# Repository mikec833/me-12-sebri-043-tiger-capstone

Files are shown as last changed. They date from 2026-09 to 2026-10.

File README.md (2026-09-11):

# The Tiger Challenge

Melbourne Zoo Sumatran tiger enrichment capstone — design context as of 11 September 2026.

## Purpose and concept

The project aims to develop a robotic enrichment system for Hutan, a Sumatran tiger at Melbourne Zoo. A mobile spherical robot is intended to encourage investigation, stalking, movement and play, then guide the tiger towards a separate feeder box that provides a food reward. Animal engagement and welfare benefits are intended outcomes, not yet demonstrated results.

The current concept uses two motor-driven internal wheels acting against the inside of a spherical shell. Differential wheel motion provides propulsion and steering. The ball carries its control electronics, sensors and battery; the food-release mechanism remains in the stationary feeder box. A speaker and amplifier are also planned for sound cues.

## Prototype and demonstration goals

A small, approximately 20 cm diameter ball is being used for early development. A larger ball is planned for the Endeavour exhibition; approximately 50 cm has been discussed, but final dimensions and hardware remain subject to mechanical development.

The intended demonstration is a robot moving within a defined space and triggering a simplified feeder box when it reaches the designated feeder zone. The box releases food or a substitute reward. This is a supervised prototype demonstration with no live tiger interaction, rather than evidence of readiness for enclosure deployment.

## System architecture

```text
Operator GUI / controller <-- wireless --> Raspberry Pi 3
                                              |
                                    UART commands / status
                                              |
                                            Teensy <-- motor encoders
                                              |
                                      Sabertooth 2x12
                                              |
                                    Two DC motors / wheels
                                              |
                                         Spherical shell

Fixed UWB anchors <--> onboard UWB tag --> localisation input to Pi
IMU / battery sensing -----------------> control and monitoring
Pi arrival logic ----------------------> separate feeder-box mechanism
Pi audio ------------------------------> amplifier --> speaker
```

| Component | Intended responsibility |
|---|---|
| Operator interface | Manual forward/reverse/turn/stop and variable speed; emergency stop; display mode, position, battery and faults. Waypoint selection and mode controls support later autonomy. |
| Raspberry Pi 3 | High-level state machine, operator communication, localisation, geofencing, navigation, feeder coordination and logging. Python is the proposed application language. |
| Teensy | Predictable motor-control timing, encoder acquisition, left/right speed targets, closed-loop speed regulation, command-timeout stopping and motor fault handling. Firmware is expected to use C/C++. |
| Sabertooth 2x12 | Converts controller commands into motor power. The exact input mode and signalling must be confirmed before wiring and implementation; earlier notes use “PWM/direction” as shorthand. |
| Power system | Planned rechargeable battery with protected motor supply and regulated electronics supplies. Current measurements will inform battery and regulator sizing. |

The proposed software uses **timed control loops plus asynchronous sensor updates**. The Pi runs a supervisory loop; callbacks or background tasks update timestamped sensor and command data. The Teensy runs a fixed-rate motor loop, with interrupts for encoder pulses. Illustrative starting rates are 10–30 Hz for supervision and 50–100 Hz for motor control, to be validated experimentally.

Only the Pi's supervisory logic selects the final requested motion; the Teensy applies motor control and local safety overrides. Sensor callbacks do not independently command motion. Suggested states are idle, manual control, autonomous navigation, geofence avoidance, fault and emergency stop.

## Sensors and interfaces

- **Ultra-wideband (UWB):** fixed anchors and one mobile tag provide position for navigation, exclusion zones and feeder proximity. Qorvo modules/development kits have been considered; hardware, anchor layout and the Pi interface still need confirmation. Accuracy must be measured with the shell, obstructions and intended environment.
- **Inertial measurement unit (IMU):** the BNO085 breakout has been discussed for orientation, angular rate, rocking measurement and possible interaction detection. Its controller connection and role in heading estimation remain to be finalised.
- **Motor encoders:** provide left/right speed feedback to the Teensy. Wheel rotation alone does not establish ball displacement because the wheels can slip against the shell.
- **Battery voltage sensing:** supports telemetry and low-voltage stopping. Motor-current sensing is a possible addition for power characterisation and fault detection.
- **Optional obstacle sensors:** time-of-flight, lidar and ultrasonic options have been explored. Mounting and sensing through a rotating shell remain unresolved.

The planned Pi–Teensy link is UART, carrying speed/turn/stop commands and returning encoder speeds, status and faults. Operator communication is expected to use Wi-Fi; alternatives remain under evaluation. Sensor fusion, including a possible Kalman filter, is an enhancement rather than an established implementation. UWB position alone does not supply heading.

## Feeder-box interaction

The longer-term sequence is: attract engagement → detect distinct tiger interactions → navigate to the selected feeder → stop in its arrival zone → request food release. One feeder is planned for prototyping, with multiple feeders a possible extension.

Draft requirements propose **three interactions separated by 30 seconds** and a **0.5 m feeder-arrival threshold**. These are provisional values to validate; older notes also mention five interactions. Detection must distinguish animal contact from driving, terrain disturbances and the robot's own rocking.

For the exhibition, reaching the feeder zone is the essential trigger; reliable tiger-interaction recognition is not a prerequisite. The feeder communication link, actuator, release confirmation and protection against repeated releases still require detailed design.

## Safety approach

The intended behaviour is stopped on startup/reset, emergency-stop priority over all movement commands, and a Teensy watchdog that stops the motors if fresh Pi commands cease. Operator-link loss must also propagate to a stop. Invalid or stale localisation prevents autonomous movement.

The Pi applies speed/acceleration limits and exclusion zones for the pond, enclosure boundary and high-risk terrain. Margins must account for localisation uncertainty and stopping distance. Battery monitoring and stall/fault detection support safe stopping; encoder-only stall detection cannot detect every slipping or trapped condition.

Emergency return is a separate proposed navigation feature and must never override an emergency stop. Mechanical containment, electrical protection and operating limits require validation before any animal trial. Exhibition operation is low-speed, supervised and confined to a controlled area, with no public handling.

## MVP and stretch scope

| Priority | Scope |
|---|---|
| Core MVP | Reliable manual driving, motor control, encoder feedback, UWB position input, basic geofencing, emergency stop, communication-loss stop and useful data logging. |
| Exhibition integration | Demonstrate movement in a defined area and repeatable arrival-triggered release from one feeder box. |
| Next-stage goals | Closed-loop performance tuning, basic waypoint navigation, safe manual/autonomous mode transitions and validated IMU-based interaction detection. |
| Stretch goals | Dynamic obstacle avoidance/path planning, richer sensor fusion, multiple feeders, camera display, emergency return and more elaborate enrichment behaviour. |

Earlier notes classify some features inconsistently, particularly mode switching and stall detection. This table expresses implementation priorities; it does not remove the need to address faults relevant to the chosen demonstration.

## Testing approach

1. **Bench tests:** verify motor direction and stopping, encoder sign/scaling, command-to-speed response and current draw. Start with open-loop characterisation before tuning feedback control.
2. **Small-ball tests:** measure traction, slip, steering and forward/backward rocking under load. Log commands, encoder speeds, IMU data and supply conditions; use these to identify the relevant dynamics and evaluate speed control and rate damping.
3. **Module and fault tests:** exercise localisation validity, geofence decisions, startup/reset, emergency stop, dropped commands, sensor loss and battery/fault handling.
4. **Integrated demonstration:** repeat travel and feeder arrival/release trials, including noisy boundary readings and repeated zone entry. Record arrival error, stopping behaviour and unintended releases.
5. **Larger prototype:** repeat identification, power measurements and controller tuning. The development method may transfer from the small ball; numerical models and gains must be revalidated.

Log timestamps, mode/state, targets, motor commands, measured speeds, UWB/IMU data, battery voltage and faults. Set measurable acceptance limits before final testing; current notes do not establish validated performance figures.

## Current development status

The project is in detailed design and early hardware/control development. A small prototype exists and noticeable forward/backward swaying has been reported. The latest discussions concern Raspberry Pi setup, motor-driver testing, current measurement, low-level controller design and integrating sensors through the two-controller architecture. Michael is leading control/software work.

There is no confirmed end-to-end demonstration, validated safety performance or completed autonomous system in the available context. Immediate work is to establish repeatable motor/encoder tests, validate power requirements, tune motion on the small ball, and integrate localisation, stopping behaviour and the feeder link in stages.

This workspace currently contains reference material and this README, not a runnable software release. Files under `sources/` are read-only synced references. This summary follows the project conversation, prioritising recent decisions and marking unresolved details rather than treating earlier suggestions as completed work.

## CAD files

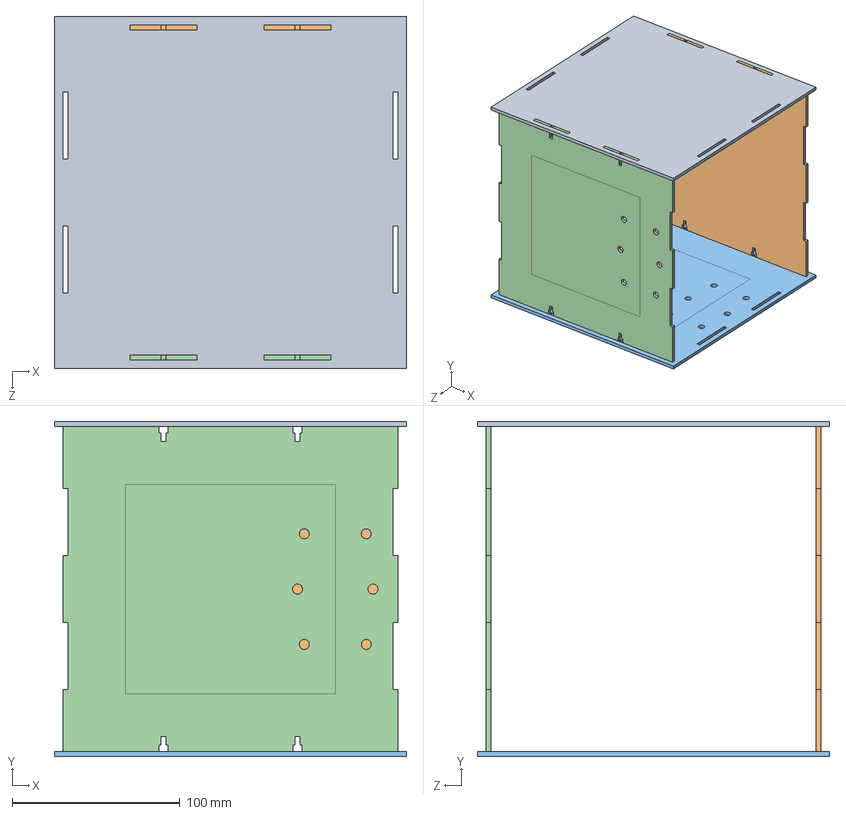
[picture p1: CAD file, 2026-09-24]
CAD File/Feeding Box CAD/Accessable.SLDASM
210.0 x 200.1 x 210.0 mm
Front
Base
Back
Top

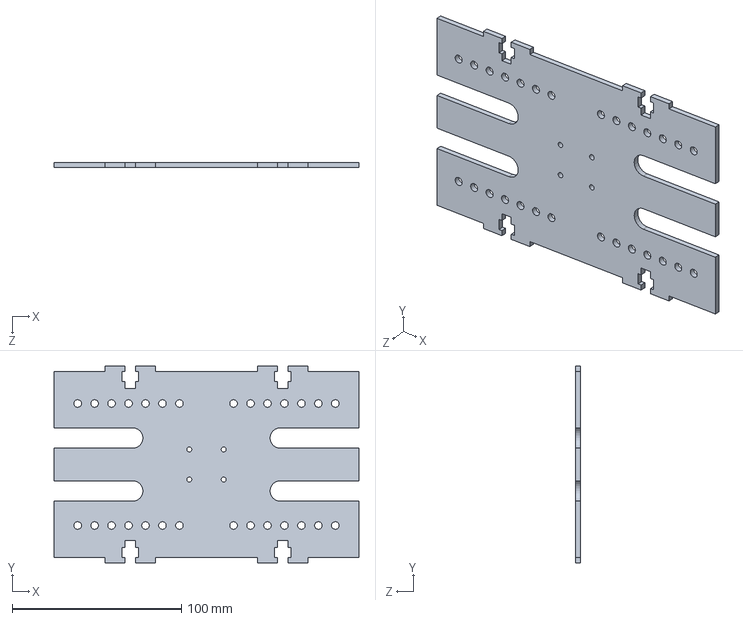
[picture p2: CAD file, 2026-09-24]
CAD File/Gig Ball Robot CAD/01_Main_Plate_3mm.SLDPRT
180.0 x 116.0 x 3.00 mm

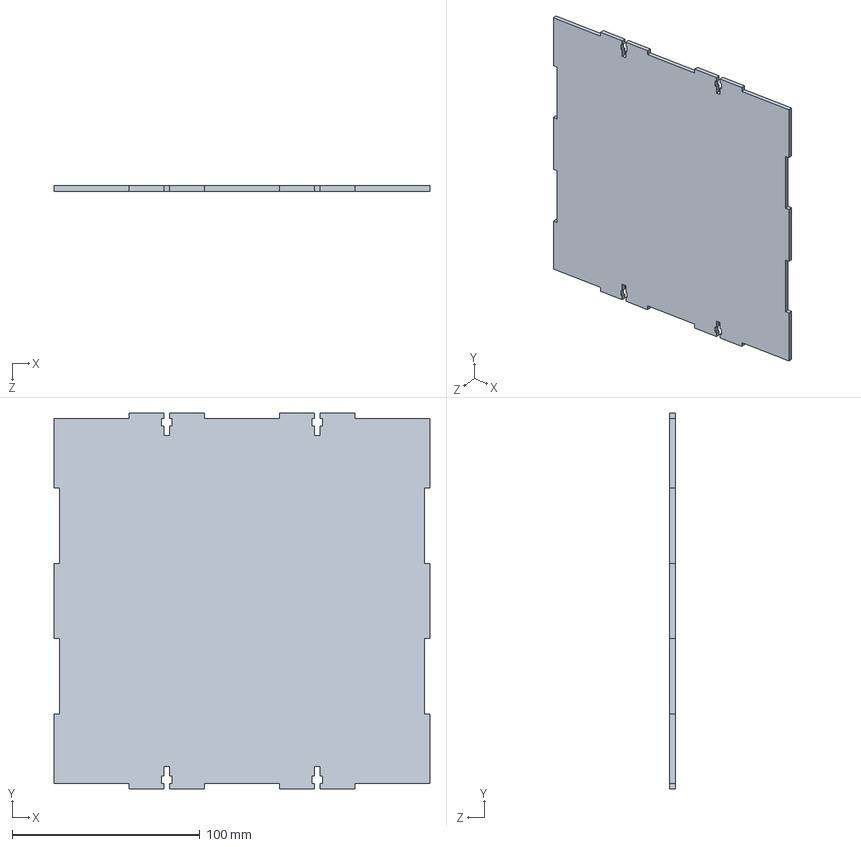
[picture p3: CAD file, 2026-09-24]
CAD File/Feeding Box CAD/Back.SLDPRT
200.0 x 200.0 x 3.00 mm

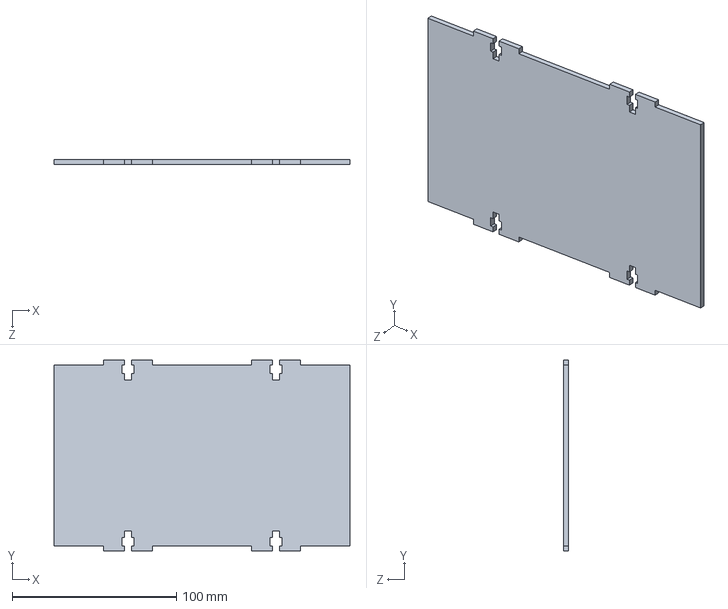
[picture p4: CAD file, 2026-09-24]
CAD File/Gig Ball Robot CAD/03_Standard_Electronics_Layer_3mm.SLDPRT
180.0 x 116.0 x 3.00 mm

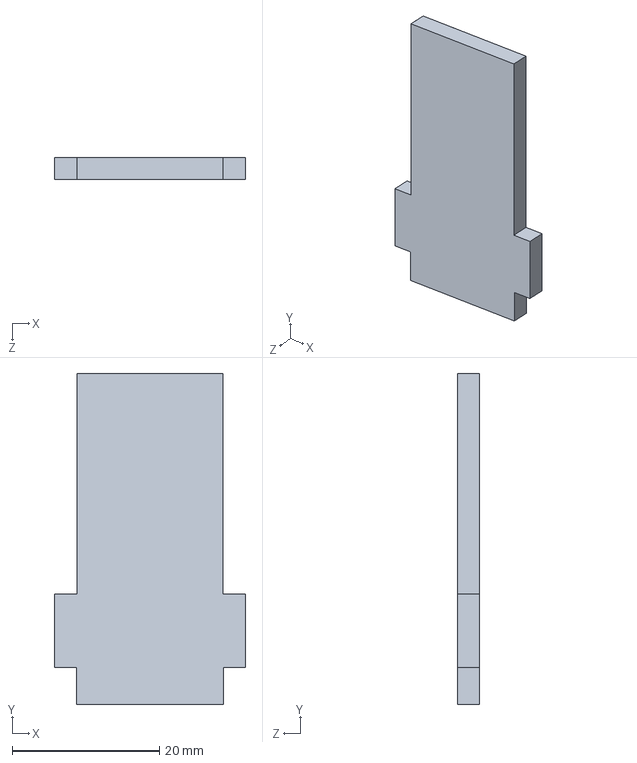
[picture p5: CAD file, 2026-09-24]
CAD File/Small Ball Robot CAD/Base Arm.SLDPRT
26.0 x 45.0 x 3.00 mm

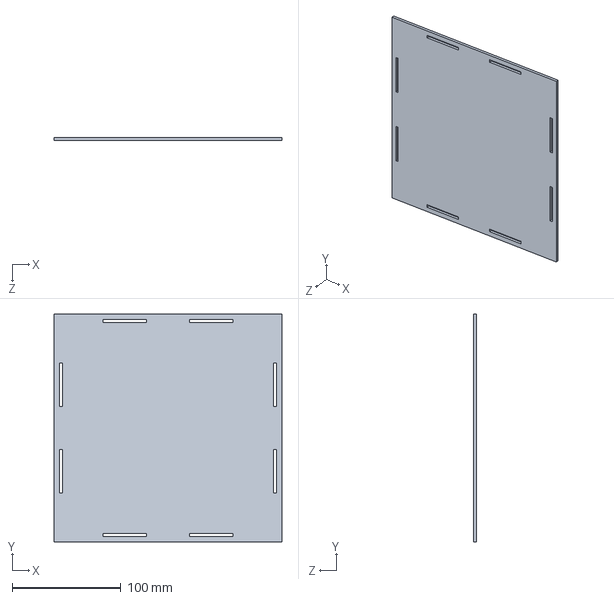
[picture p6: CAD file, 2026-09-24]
CAD File/Feeding Box CAD/Top.SLDPRT
210.0 x 210.0 x 3.00 mm

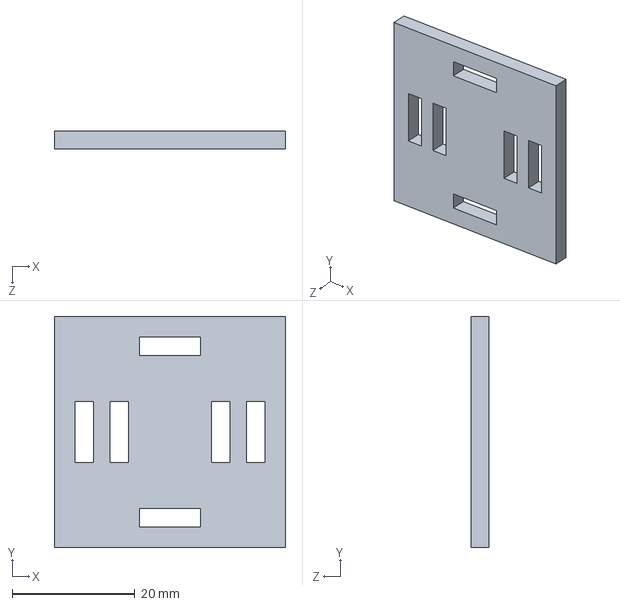
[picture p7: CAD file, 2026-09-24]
CAD File/Gig Ball Robot CAD/09_Spring_Top_Cover_3mm.SLDPRT
37.6 x 37.6 x 3.00 mm

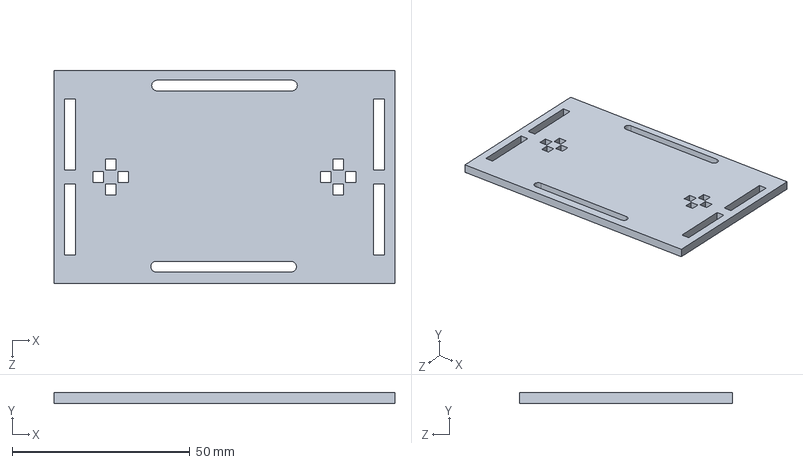
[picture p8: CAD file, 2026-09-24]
CAD File/Small Ball Robot CAD/Chasis Upper Base.SLDPRT
96.0 x 3.00 x 60.0 mm

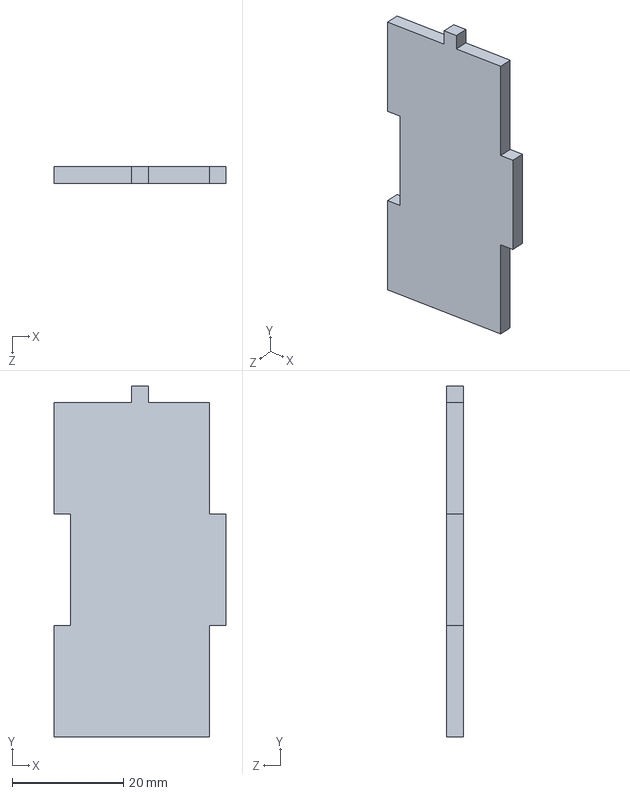
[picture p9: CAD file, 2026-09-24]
CAD File/Gig Ball Robot CAD/08_Moving_Spring_Housing_Wall_3mm.SLDPRT
30.9 x 63.0 x 3.00 mm

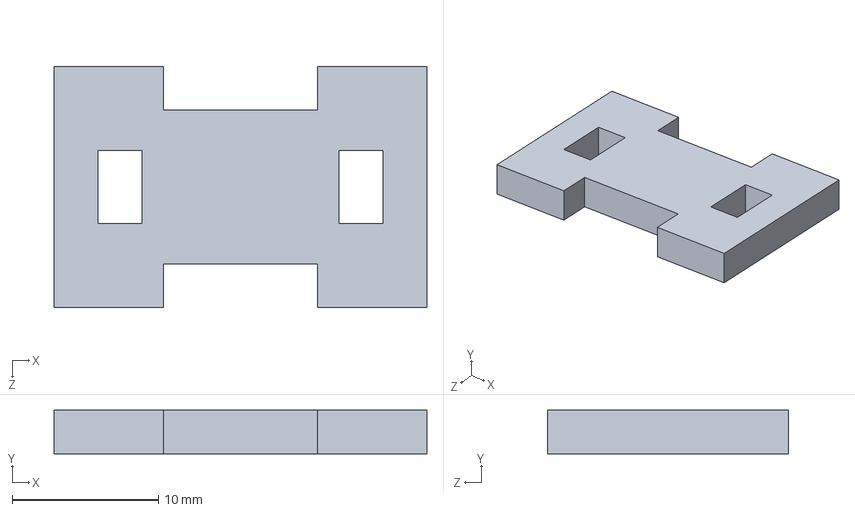
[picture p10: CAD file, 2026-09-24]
CAD File/Small Ball Robot CAD/Sping Top Cover.SLDPRT
25.5 x 3.00 x 16.5 mm

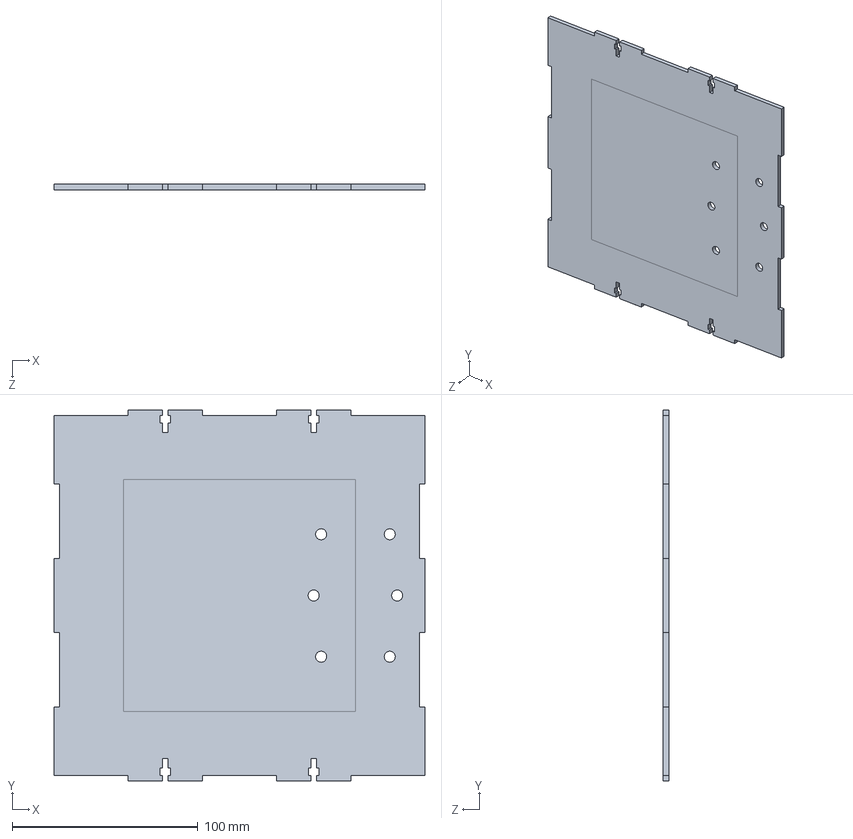
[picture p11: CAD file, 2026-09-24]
CAD File/Feeding Box CAD/Front.SLDPRT
200.0 x 200.0 x 3.00 mm

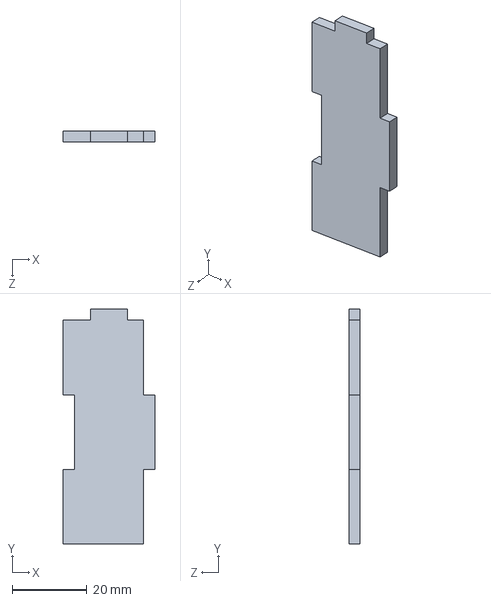
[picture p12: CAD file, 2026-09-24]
CAD File/Gig Ball Robot CAD/07_Fixed_Spring_Guide_Wall_3mm.SLDPRT
24.6 x 63.0 x 3.00 mm

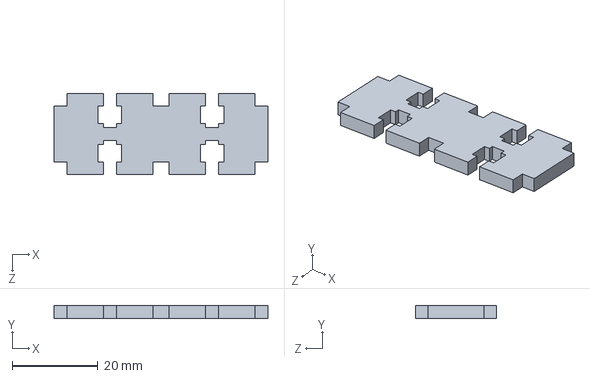
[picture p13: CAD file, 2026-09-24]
CAD File/Small Ball Robot CAD/Weight Support.SLDPRT
50.0 x 3.00 x 19.0 mm

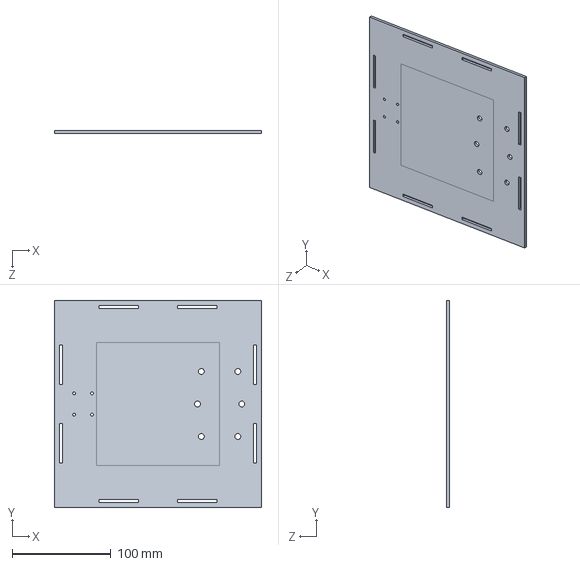
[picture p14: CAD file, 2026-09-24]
CAD File/Feeding Box CAD/Base.SLDPRT
210.0 x 210.0 x 3.00 mm

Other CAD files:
CAD File/Gig Ball Robot CAD/TigerBall_Chassis_220mm_Track_Editable.SLDASM
CAD File/Small Ball Robot CAD/Assembled Spring Support.SLDASM
CAD File/Gig Ball Robot CAD/02_Motor_Carrier_3mm.SLDPRT
CAD File/Small Ball Robot CAD/Wheel Support.SLDPRT
CAD File/Feeding Box CAD/Sides.SLDPRT
CAD File/Gig Ball Robot CAD/04_Raspberry_Pi_3_Layer_3mm.SLDPRT
CAD File/Gig Ball Robot CAD/05_Extended_Sideboard_322mm_3mm.SLDPRT
CAD File/Gig Ball Robot CAD/06_Dual_Spring_Shelf_3mm.SLDPRT
CAD File/Gig Ball Robot CAD/10_Upper_Wheel_Fork_3mm.SLDPRT
CAD File/Gig Ball Robot CAD/11_Battery_Plate_3mm.SLDPRT
CAD File/Gig Ball Robot CAD/Spring Wheel.SLDPRT
CAD File/Gig Ball Robot CAD/Spring_Cover_Front.SLDPRT
CAD File/Gig Ball Robot CAD/Spring_Cover_Side.SLDPRT
CAD File/Gig Ball Robot CAD/Wheel_Support.SLDPRT
CAD File/Small Ball Robot CAD/Battery Base.SLDPRT
CAD File/Small Ball Robot CAD/Battery Support.SLDPRT
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

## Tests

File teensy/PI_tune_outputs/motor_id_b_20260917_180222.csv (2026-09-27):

t_ms | refL | refR | cmdL | cmdR | countL | countR | thdotL | thdotR
10 | 0.00 | 0.00 | 0.00 | 0.00 | 0 | 0 | 0.000 | 0.000
20 | 0.00 | 0.00 | 0.00 | 0.00 | 0 | 0 | 0.000 | 0.000
30 | 0.00 | 0.00 | 0.00 | 0.00 | 0 | 0 | 0.000 | 0.000
40 | 0.00 | 0.00 | 0.00 | 0.00 | 0 | 0 | 0.000 | 0.000
50 | 0.00 | 0.00 | 0.00 | 0.00 | 0 | 0 | 0.000 | 0.000
60 | 0.00 | 0.00 | 0.00 | 0.00 | 0 | 0 | 0.000 | 0.000
70 | 0.00 | 0.00 | 0.00 | 0.00 | 0 | 0 | 0.000 | 0.000
80 | 0.00 | 0.00 | 0.00 | 0.00 | 0 | 0 | 0.000 | 0.000
90 | 0.00 | 0.00 | 0.00 | 0.00 | 0 | 0 | 0.000 | 0.000
100 | 0.00 | 0.00 | 0.00 | 0.00 | 0 | 0 | 0.000 | 0.000
110 | 0.00 | 0.00 | 0.00 | 0.00 | 0 | 0 | 0.000 | 0.000
120 | 0.00 | 0.00 | 0.00 | 0.00 | 0 | 0 | 0.000 | 0.000
130 | 0.00 | 0.00 | 0.00 | 0.00 | 0 | 0 | 0.000 | 0.000
140 | 0.00 | 0.00 | 0.00 | 0.00 | 0 | 0 | 0.000 | 0.000
150 | 0.00 | 0.00 | 0.00 | 0.00 | 0 | 0 | 0.000 | 0.000
160 | 0.00 | 0.00 | 0.00 | 0.00 | 0 | 0 | 0.000 | 0.000
170 | 0.00 | 0.00 | 0.00 | 0.00 | 0 | 0 | 0.000 | 0.000
180 | 0.00 | 0.00 | 0.00 | 0.00 | 0 | 0 | 0.000 | 0.000
190 | 0.00 | 0.00 | 0.00 | 0.00 | 0 | 0 | 0.000 | 0.000
200 | 0.00 | 0.00 | 0.00 | 0.00 | 0 | 0 | 0.000 | 0.000
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

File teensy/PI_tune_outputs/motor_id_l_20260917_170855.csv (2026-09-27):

t_ms | cmdL | cmdR | countL | countR | thdotL | thdotR
10 | 0 | 0 | 4 | 0 | 0.561 | 0.000
20 | 0 | 0 | 9 | 0 | 0.701 | 0.000
30 | 0 | 0 | 14 | 0 | 0.701 | 0.000
40 | 0 | 0 | 19 | 0 | 0.701 | 0.000
50 | 0 | 0 | 23 | 0 | 0.561 | 0.000
60 | 0 | 0 | 28 | 0 | 0.701 | 0.000
70 | 0 | 0 | 33 | 0 | 0.701 | 0.000
80 | 0 | 0 | 37 | 0 | 0.561 | 0.000
90 | 0 | 0 | 42 | 0 | 0.701 | 0.000
100 | 0 | 0 | 46 | 0 | 0.561 | 0.000
110 | 0 | 0 | 49 | 0 | 0.421 | 0.000
120 | 0 | 0 | 53 | 0 | 0.561 | 0.000
130 | 0 | 0 | 57 | 0 | 0.561 | 0.000
140 | 0 | 0 | 60 | 0 | 0.421 | 0.000
150 | 0 | 0 | 63 | 0 | 0.421 | 0.000
160 | 0 | 0 | 67 | 0 | 0.561 | 0.000
170 | 0 | 0 | 71 | 0 | 0.561 | 0.000
180 | 0 | 0 | 75 | 0 | 0.561 | 0.000
190 | 0 | 0 | 78 | 0 | 0.421 | 0.000
200 | 0 | 0 | 82 | 0 | 0.561 | 0.000
210 | 0 | 0 | 86 | 0 | 0.561 | 0.000
220 | 0 | 0 | 89 | 0 | 0.421 | 0.000
230 | 0 | 0 | 93 | 0 | 0.561 | 0.000
240 | 0 | 0 | 96 | 0 | 0.421 | 0.000
250 | 0 | 0 | 100 | 0 | 0.561 | 0.000
260 | 0 | 0 | 104 | 0 | 0.561 | 0.000
270 | 0 | 0 | 109 | 0 | 0.701 | 0.000
280 | 0 | 0 | 114 | 0 | 0.701 | 0.000
290 | 0 | 0 | 118 | 0 | 0.561 | 0.000
300 | 0 | 0 | 123 | 0 | 0.701 | 0.000
310 | 0 | 0 | 128 | 0 | 0.701 | 0.000
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

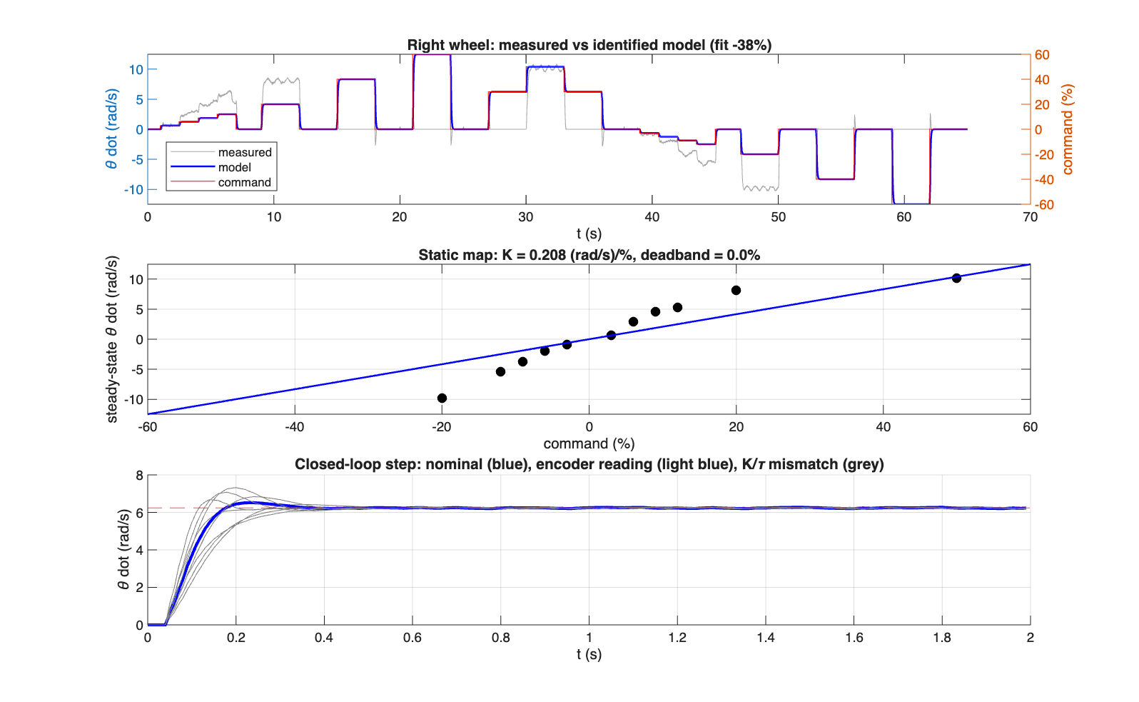
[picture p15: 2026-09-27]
teensy/PI_tune_outputs/right_run1_60pc.png

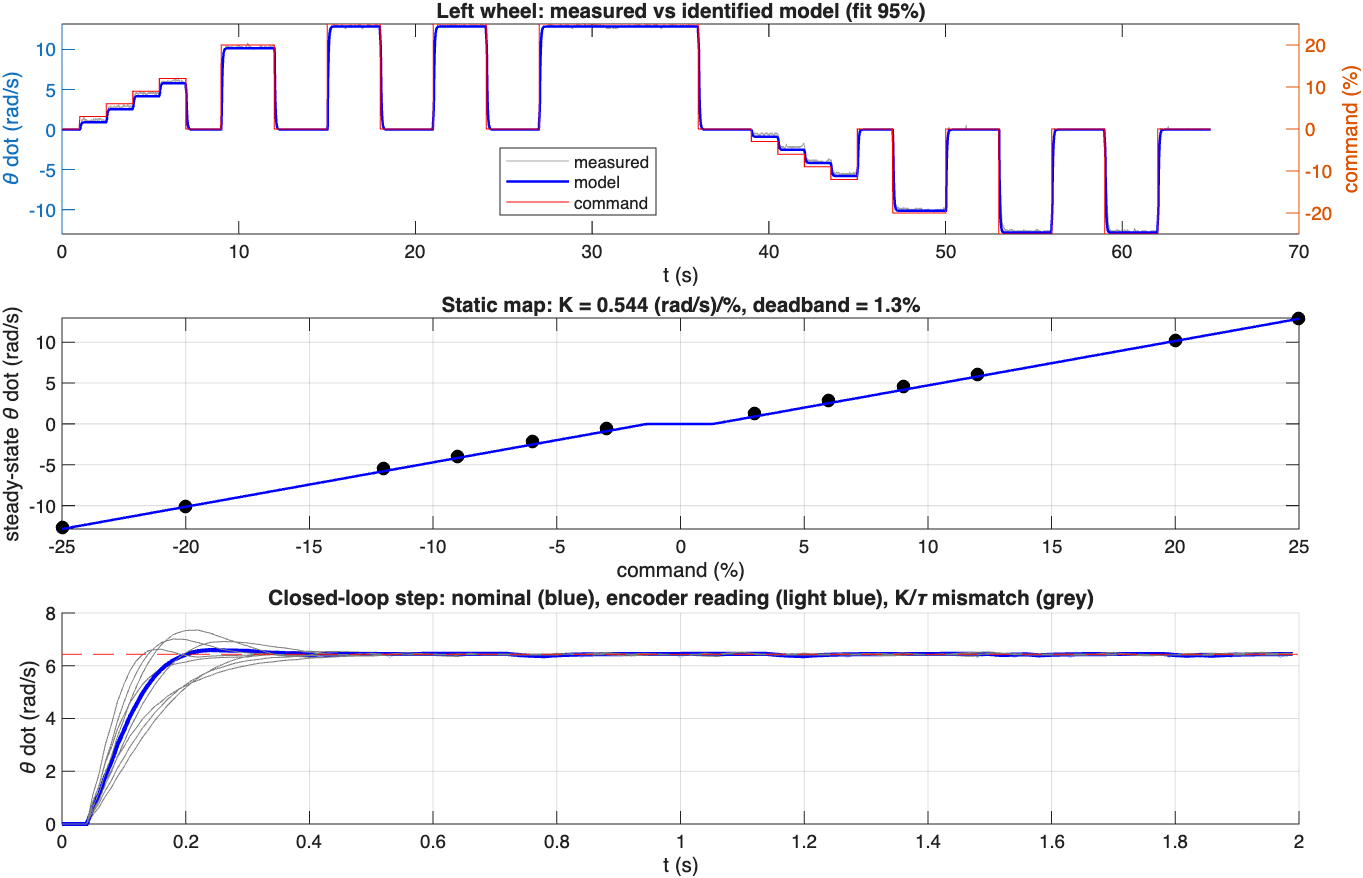
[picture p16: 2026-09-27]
teensy/PI_tune_outputs/left_run2_25pc.png

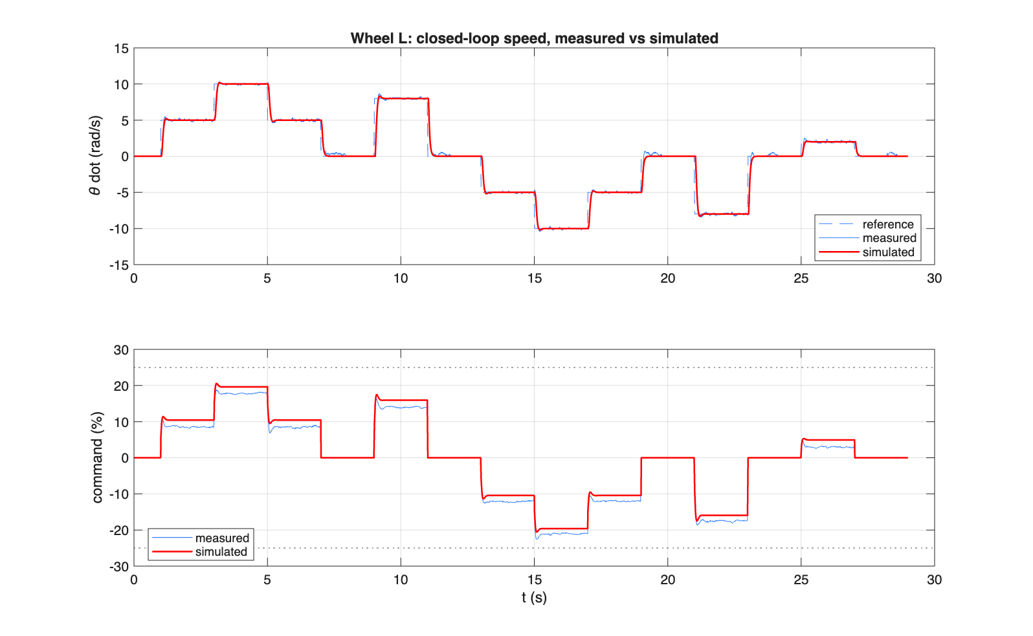
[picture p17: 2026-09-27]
teensy/PI_tune_outputs/CL_left_run_comp.png

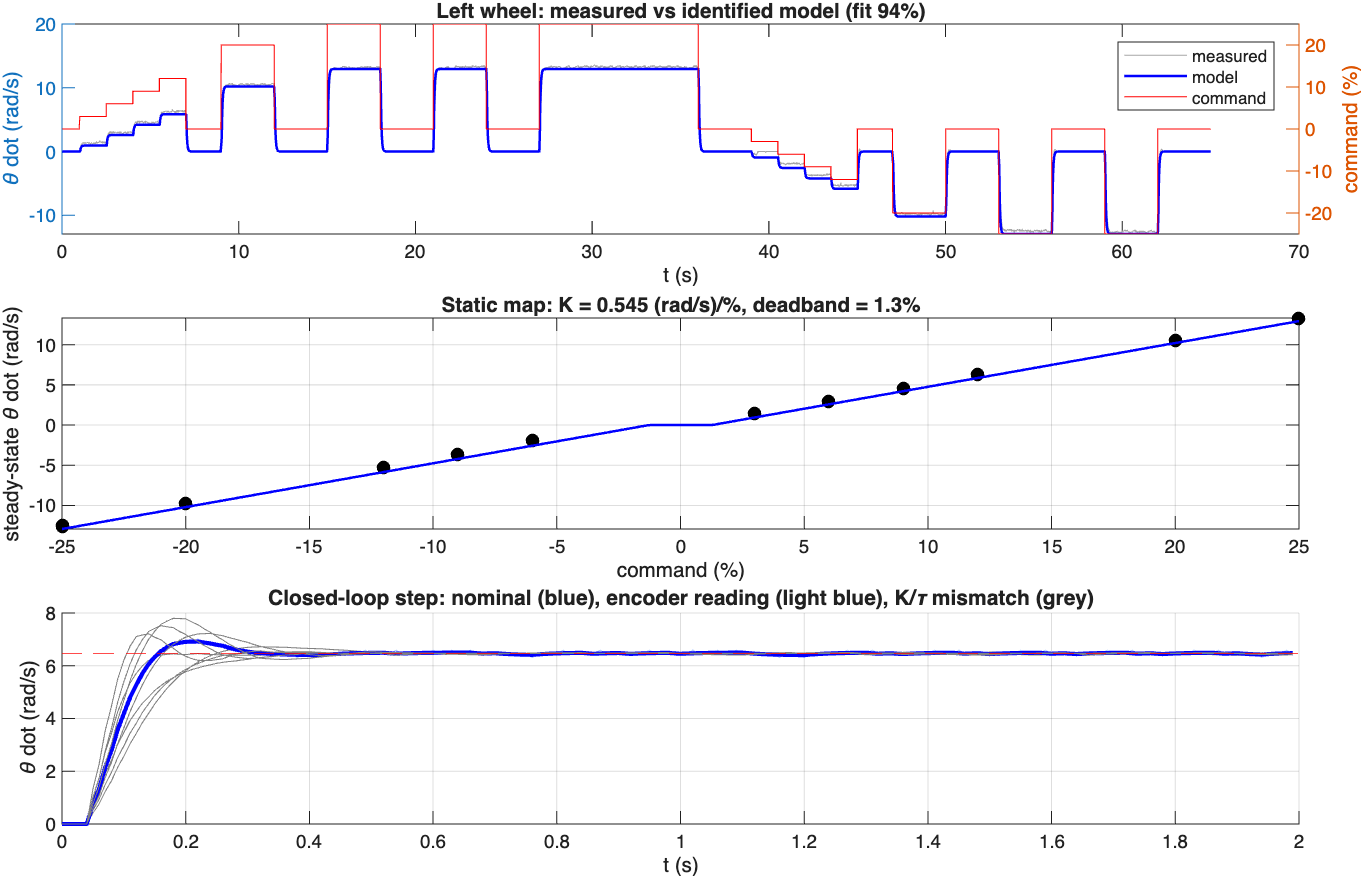
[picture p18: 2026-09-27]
teensy/PI_tune_outputs/left_run3_25pc.png

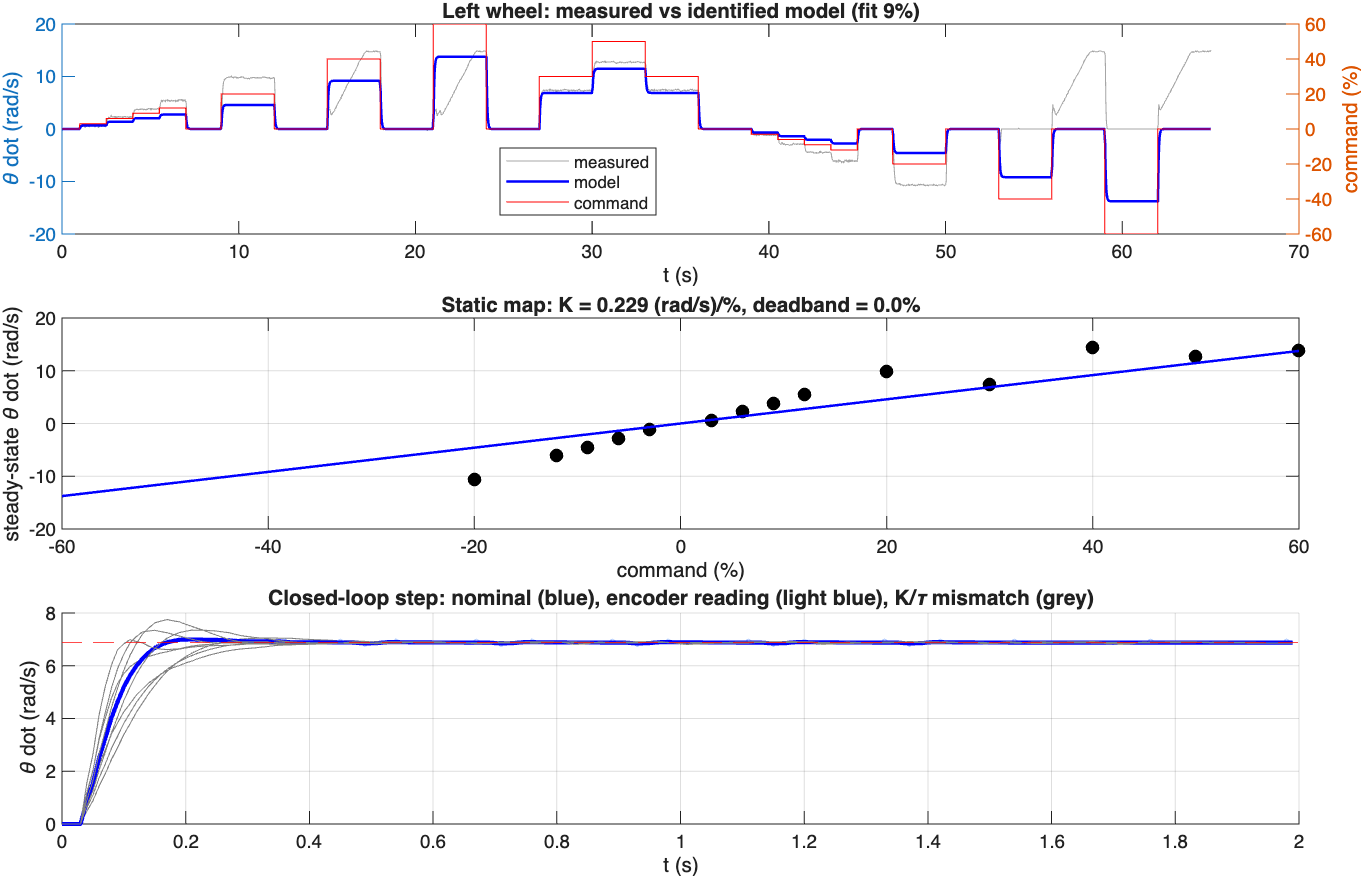
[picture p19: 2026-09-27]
teensy/PI_tune_outputs/left_run1_60pc.png

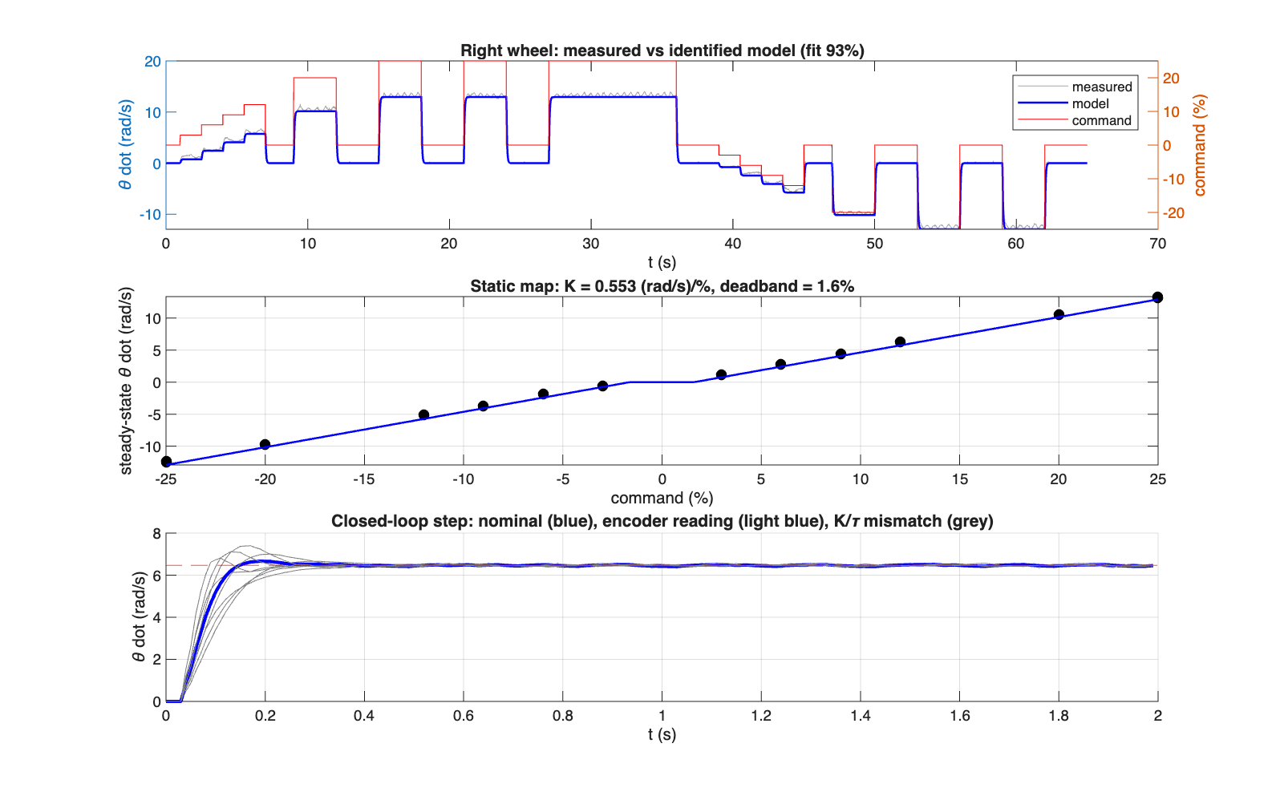
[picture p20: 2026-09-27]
teensy/PI_tune_outputs/right_run3_25pc.png

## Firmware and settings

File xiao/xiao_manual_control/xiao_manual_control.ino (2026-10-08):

#include <Arduino.h>
#include <Adafruit_TinyUSB.h>
#include <bluefruit.h>
#include <Servo.h>
 
// TigerBall 500 mm bench controller: XIAO nRF52840 -> Sabertooth 2x12.
// Arduino board package: Seeed nRF52 Boards (non-mbed).
// Use the Bluefruit and Servo libraries bundled with that board package.
// Sabertooth must be physically configured for independent R/C input mode.
 
constexpr uint8_t LEFT_MOTOR_PIN = D10;   // Sabertooth S1
constexpr uint8_t RIGHT_MOTOR_PIN = D8;   // Sabertooth S2
constexpr uint8_t LEFT_ENCODER_A = D5;    // motor 1 yellow, through level shifter
constexpr uint8_t LEFT_ENCODER_B = D6;    // motor 1 white, through level shifter
constexpr uint8_t RIGHT_ENCODER_A = D3;   // motor 2 yellow, through level shifter
constexpr uint8_t RIGHT_ENCODER_B = D4;   // motor 2 white, through level shifter
constexpr uint8_t BATTERY_PIN = D0;        // switched pack + through 5.54k/979R divider
constexpr float BATTERY_R1_OHMS = 5540.0f;
constexpr float BATTERY_R2_OHMS = 979.0f;
constexpr float BATTERY_ADC_RANGE_V = 3.0f;  // AR_INTERNAL_3_0, not the 3.3 V GPIO rail
constexpr float BATTERY_ADC_MAX_COUNT = 4095.0f; // 12-bit ADC
constexpr uint32_t BATTERY_INTERVAL_MS = 1000;
constexpr uint32_t LED_TOGGLE_INTERVAL_MS = 100; // 100 ms on + 100 ms off = 5 Hz
constexpr float LOW_BATTERY_TRIP_V = 10.0f;
constexpr float LOW_BATTERY_CLEAR_V = 10.3f;
 
constexpr float batteryVoltageFromAdc(uint16_t count) {
  return count * BATTERY_ADC_RANGE_V / BATTERY_ADC_MAX_COUNT *
    (BATTERY_R1_OHMS + BATTERY_R2_OHMS) / BATTERY_R2_OHMS;
}
static_assert(batteryVoltageFromAdc(2650) > 12.9f &&
              batteryVoltageFromAdc(2650) < 13.0f,
              "Battery divider/ADC conversion does not match measured 979 ohm divider");
 
constexpr int NEUTRAL_US = 1500;
constexpr int FULL_REVERSE_US = 1000;
constexpr int FULL_FORWARD_US = 2000;
constexpr float OUTPUT_LIMIT_PERCENT = 100.0f;
constexpr uint32_t PIVOT_RESPONSE_MS = 100;
 
// Pololu #2825: 64 counts/motor revolution * 70:1 = 4480 counts/output rev
// when all four quadrature edges are counted.
constexpr float COUNTS_PER_OUTPUT_REV = 4480.0f;
constexpr uint32_t CONTROL_INTERVAL_MS = 20;
constexpr uint32_t SPEED_INTERVAL_MS = 100;
constexpr uint32_t TELEMETRY_INTERVAL_MS = 250;
constexpr uint32_t SOFT_TIMEOUT_MS = 500;
constexpr uint32_t HARD_TIMEOUT_MS = 1200;
 
// Straight-line synchroniser. These are conservative starting values and must
// be tuned wheels-raised before loaded use.
constexpr float SYNC_MIN_COMMAND_PERCENT = 12.0f;
constexpr float SYNC_KP_PERCENT_PER_RPM = 0.18f;
constexpr float SYNC_KI_PERCENT_PER_RPM_SECOND = 0.04f;
constexpr float SYNC_MAX_CORRECTION_PERCENT = 10.0f;
constexpr float STALL_MOVING_RPM = 8.0f;
constexpr float STALL_STOPPED_RPM = 1.0f;
constexpr uint32_t STALL_TIME_MS = 800;
// A reversal waits for neutral PWM and two fresh, near-zero encoder samples.
// This is a best-effort software interlock, not motor-current protection.
constexpr float REVERSAL_STOP_RPM = 1.0f;
constexpr uint8_t REVERSAL_STOP_SAMPLES = 2;
 
const char *DEVICE_NAME = "TigerBall-50-XIAO";
const char *SERVICE_UUID = "6e400001-b5a3-f393-e0a9-e50e24dcca9e";
const char *RX_UUID = "6e400002-b5a3-f393-e0a9-e50e24dcca9e";
const char *TX_UUID = "6e400003-b5a3-f393-e0a9-e50e24dcca9e";
 
BLEService motorService(SERVICE_UUID);
BLECharacteristic rxCharacteristic(RX_UUID);
BLECharacteristic txCharacteristic(TX_UUID);
Servo leftMotor;
Servo rightMotor;
volatile bool bleConnected = false;
String receiveBuffer;
 
volatile int32_t leftCount = 0;
volatile int32_t rightCount = 0;
volatile uint8_t leftPreviousState = 0;
volatile uint8_t rightPreviousState = 0;
 
float leftRpm = 0.0f;
float rightRpm = 0.0f;
float targetLeft = 0.0f;
float targetRight = 0.0f;
float requestedLeft = 0.0f;
float requestedRight = 0.0f;
float rampedLeft = 0.0f;
float rampedRight = 0.0f;
float appliedLeft = 0.0f;
float appliedRight = 0.0f;
bool requestedDirectPivot = false;
bool rampPivotMode = false;
float motionEnvelope = 0.0f;
bool waitingForNeutral = false;
uint8_t stoppedSamples = 0;
int8_t recentLeftSign = 0;
int8_t recentRightSign = 0;
float syncIntegral = 0.0f;
float syncCorrection = 0.0f;
uint32_t accelerationMs = 800;
uint32_t brakingMs = 700;
float configuredMaximumPercent = 10.0f;
uint32_t lastCommandMs = 0;
uint32_t lastControlMs = 0;
uint32_t lastSpeedMs = 0;
uint32_t lastTelemetryMs = 0;
uint32_t lastBatteryMs = 0;
uint32_t lastLedToggleMs = 0;
float batteryVoltage = 0.0f;
bool lowBattery = false;
bool redLedOn = false;
uint32_t stallStartedMs = 0;
bool armed = false;
bool stallFault = false;
 
constexpr int8_t QUADRATURE_TABLE[16] = {
  0, -1, 1, 0,
  1, 0, 0, -1,
  -1, 0, 0, 1,
  0, 1, -1, 0
};
 
float clampOutput(float value) {
  return constrain(value, -configuredMaximumPercent, configuredMaximumPercent);
}
 
int8_t commandSign(float value) {
  return value > 0.5f ? 1 : (value < -0.5f ? -1 : 0);
}
 
float signOf(float value) {
  return value < 0.0f ? -1.0f : 1.0f;
}
 
void attachMotorPwm() {
  // The nRF52 Servo library generates hardware PWM with a 20 ms period.
  leftMotor.attach(LEFT_MOTOR_PIN, FULL_REVERSE_US, FULL_FORWARD_US);
  rightMotor.attach(RIGHT_MOTOR_PIN, FULL_REVERSE_US, FULL_FORWARD_US);
}
 
void applyMotorOutputs(float leftPercent, float rightPercent) {
  // Keep command-mode changes from interleaving with the final output clamp.
  taskENTER_CRITICAL();
  leftPercent = clampOutput(leftPercent);
  rightPercent = clampOutput(rightPercent);
  const int leftUs = NEUTRAL_US + lroundf(leftPercent * 5.0f);
  const int rightUs = NEUTRAL_US + lroundf(rightPercent * 5.0f);
  leftMotor.writeMicroseconds(constrain(leftUs, FULL_REVERSE_US, FULL_FORWARD_US));
  rightMotor.writeMicroseconds(constrain(rightUs, FULL_REVERSE_US, FULL_FORWARD_US));
  appliedLeft = leftPercent;
  appliedRight = rightPercent;
  if (commandSign(leftPercent)) recentLeftSign = commandSign(leftPercent);
  if (commandSign(rightPercent)) recentRightSign = commandSign(rightPercent);
  taskEXIT_CRITICAL();
}
 
void resetSynchroniser() {
  syncIntegral = 0.0f;
  syncCorrection = 0.0f;
  stallStartedMs = 0;
}
 
void neutralAndDisarm() {
  requestedLeft = 0.0f;
  requestedRight = 0.0f;
  requestedDirectPivot = false;
  waitingForNeutral = false;
  targetLeft = 0.0f;
  targetRight = 0.0f;
  rampedLeft = 0.0f;
  rampedRight = 0.0f;
  motionEnvelope = 0.0f;
  rampPivotMode = false;
  resetSynchroniser();
  applyMotorOutputs(0.0f, 0.0f);
  // A new arm needs a fresh C command; stale high-output settings do not
  // survive a disconnect, fault, STOP, or tab-change disarm.
  configuredMaximumPercent = 10.0f;
  armed = false;
}
 
void notifyLine(const String &line) {
  if (!bleConnected || !txCharacteristic.notifyEnabled()) return;
  // Stay within the default 20-byte BLE notification payload. The website
  // reassembles newline-terminated messages across notifications.
  for (size_t offset = 0; offset < line.length(); offset += 20) {
    const size_t chunk = min(static_cast<size_t>(20), line.length() - offset);
    txCharacteristic.notify(line.c_str() + offset, chunk);
  }
}
 
void setTargets(float left, float right, bool directPivot) {
  if (!armed || stallFault) return;
  requestedLeft = clampOutput(left);
  requestedRight = clampOutput(right);
  requestedDirectPivot = directPivot;
  if (commandSign(requestedLeft) == 0 && commandSign(requestedRight) == 0) {
    waitingForNeutral = false;
    targetLeft = 0.0f;
    targetRight = 0.0f;
  } else if (waitingForNeutral) {
    // Latest request wins, but no new direction runs until both wheels stop.
    targetLeft = 0.0f;
    targetRight = 0.0f;
  } else {
    const bool leftReverses = commandSign(requestedLeft) && recentLeftSign &&
      commandSign(requestedLeft) != recentLeftSign;
    const bool rightReverses = commandSign(requestedRight) && recentRightSign &&
      commandSign(requestedRight) != recentRightSign;
    // Gate entry into a pivot from a moving non-pivot command, but do not
    // re-gate every 100 ms heartbeat after that same pivot has started.
    if (leftReverses || rightReverses ||
        (directPivot && !rampPivotMode && stoppedSamples < REVERSAL_STOP_SAMPLES &&
         (fabsf(leftRpm) > REVERSAL_STOP_RPM || fabsf(rightRpm) > REVERSAL_STOP_RPM))) {
      waitingForNeutral = true;
      stoppedSamples = 0;
      targetLeft = 0.0f;
      targetRight = 0.0f;
      notifyLine("STATE,WAIT_NEUTRAL\n");
    } else {
      targetLeft = requestedLeft;
      targetRight = requestedRight;
      rampPivotMode = directPivot;
    }
  }
  lastCommandMs = millis();
}
 
float stepEnvelope(float current, float target, float dtSeconds) {
  const bool slowing = target < current;
  const uint32_t requestedDuration = rampPivotMode ? PIVOT_RESPONSE_MS :
    (slowing ? brakingMs : accelerationMs);
  const float durationSeconds = requestedDuration / 1000.0f;
  // The selected full output, not 100%, takes the selected ramp duration.
  const float maximumStep = (configuredMaximumPercent / durationSeconds) * dtSeconds;
  if (target > current) return min(current + maximumStep, target);
  if (target < current) return max(current - maximumStep, target);
  return current;
}
 
void updateLeftEncoder() {
  const uint8_t state = (digitalRead(LEFT_ENCODER_A) << 1) | digitalRead(LEFT_ENCODER_B);
  const uint8_t index = (leftPreviousState << 2) | state;
  leftCount += QUADRATURE_TABLE[index];
  leftPreviousState = state;
}
 
void updateRightEncoder() {
  const uint8_t state = (digitalRead(RIGHT_ENCODER_A) << 1) | digitalRead(RIGHT_ENCODER_B);
  const uint8_t index = (rightPreviousState << 2) | state;
  rightCount += QUADRATURE_TABLE[index];
  rightPreviousState = state;
}
 
void updateSpeedEstimate(uint32_t now) {
  static int32_t previousLeftCount = 0;
  static int32_t previousRightCount = 0;
  const uint32_t elapsedMs = now - lastSpeedMs;
  if (elapsedMs < SPEED_INTERVAL_MS) return;
 
  int32_t currentLeftCount;
  int32_t currentRightCount;
  taskENTER_CRITICAL();
  currentLeftCount = leftCount;
  currentRightCount = rightCount;
  taskEXIT_CRITICAL();
 
  const float rpmFactor = 60000.0f / (COUNTS_PER_OUTPUT_REV * elapsedMs);
  leftRpm = (currentLeftCount - previousLeftCount) * rpmFactor;
  rightRpm = (currentRightCount - previousRightCount) * rpmFactor;
  previousLeftCount = currentLeftCount;
  previousRightCount = currentRightCount;
  lastSpeedMs = now;
 
  const bool neutralAndStopped =
    fabsf(rampedLeft) <= 0.5f && fabsf(rampedRight) <= 0.5f &&
    fabsf(appliedLeft) <= 0.5f && fabsf(appliedRight) <= 0.5f &&
    fabsf(leftRpm) <= REVERSAL_STOP_RPM &&
    fabsf(rightRpm) <= REVERSAL_STOP_RPM;
  stoppedSamples = neutralAndStopped ? min(static_cast<int>(stoppedSamples) + 1,
    static_cast<int>(REVERSAL_STOP_SAMPLES)) : 0;
  if (stoppedSamples >= REVERSAL_STOP_SAMPLES) {
    recentLeftSign = 0;
    recentRightSign = 0;
    if (waitingForNeutral) {
      waitingForNeutral = false;
      targetLeft = requestedLeft;
      targetRight = requestedRight;
      if (commandSign(targetLeft) || commandSign(targetRight))
        rampPivotMode = requestedDirectPivot;
      notifyLine("STATE,NEUTRAL_READY\n");
    }
  }
}
 
bool straightSynchronisationRequested() {
  if (!armed || stallFault) return false;
  if (targetLeft * targetRight <= 0.0f) return false;
  if (fabsf(targetLeft) < SYNC_MIN_COMMAND_PERCENT || fabsf(targetRight) < SYNC_MIN_COMMAND_PERCENT) return false;
  if (fabsf(rampedLeft) < SYNC_MIN_COMMAND_PERCENT || fabsf(rampedRight) < SYNC_MIN_COMMAND_PERCENT) return false;
  return fabsf(fabsf(targetLeft) - fabsf(targetRight)) <= 1.0f;
}
 
void updateSynchroniser(float dtSeconds, uint32_t now) {
  if (!straightSynchronisationRequested()) {
    resetSynchroniser();
    applyMotorOutputs(rampedLeft, rampedRight);
    return;
  }
 
  const float leftSpeed = fabsf(leftRpm);
  const float rightSpeed = fabsf(rightRpm);
  const float errorRpm = leftSpeed - rightSpeed;
  syncIntegral = constrain(syncIntegral + errorRpm * dtSeconds, -100.0f, 100.0f);
  const float correctionLimit = min(SYNC_MAX_CORRECTION_PERCENT,
    0.5f * min(fabsf(rampedLeft), fabsf(rampedRight)));
  syncCorrection = constrain(
    SYNC_KP_PERCENT_PER_RPM * errorRpm + SYNC_KI_PERCENT_PER_RPM_SECOND * syncIntegral,
    -correctionLimit,
    correctionLimit
  );
 
  const float correctedLeft = rampedLeft - signOf(rampedLeft) * syncCorrection;
  const float correctedRight = rampedRight + signOf(rampedRight) * syncCorrection;
  applyMotorOutputs(correctedLeft, correctedRight);
 
  const bool oneWheelStalled =
    (leftSpeed < STALL_STOPPED_RPM && rightSpeed > STALL_MOVING_RPM) ||
    (rightSpeed < STALL_STOPPED_RPM && leftSpeed > STALL_MOVING_RPM);
  const bool bothWheelsStopped =
    fabsf(rampedLeft) >= SYNC_MIN_COMMAND_PERCENT &&
    fabsf(rampedRight) >= SYNC_MIN_COMMAND_PERCENT &&
    leftSpeed < STALL_STOPPED_RPM && rightSpeed < STALL_STOPPED_RPM;
  if (oneWheelStalled || bothWheelsStopped) {
    if (stallStartedMs == 0) stallStartedMs = now;
    if (now - stallStartedMs >= STALL_TIME_MS) {
      stallFault = true;
      neutralAndDisarm();
      notifyLine("FAULT,ENCODER_STALL\n");
    }
  } else {
    stallStartedMs = 0;
  }
}
 
void processCommand(String command) {
  command.trim();
  if (command.length() == 0) return;
 
  if (command == "V") {
    notifyLine("VERSION,4.6\n");
    return;
  }
 
  if (command == "A") {
    if (!stallFault) {
      const float armedMaximum = configuredMaximumPercent;
      neutralAndDisarm();
      configuredMaximumPercent = armedMaximum;
      armed = true;
      lastCommandMs = millis();
      notifyLine("STATE,ARMED\n");
    }
    return;
  }
  if (command == "K") {
    neutralAndDisarm();
    notifyLine("STATE,DISARMED\n");
    return;
  }
  if (command == "R") {
    neutralAndDisarm();
    stallFault = false;
    notifyLine("STATE,FAULT_RESET\n");
    return;
  }
  if (command == "S") {
    if (armed) {
      requestedLeft = 0.0f;
      requestedRight = 0.0f;
      requestedDirectPivot = false;
      waitingForNeutral = false;
      targetLeft = 0.0f;
      targetRight = 0.0f;
      lastCommandMs = millis();
    }
    return;
  }
 
  // This board package does not enable floating-point sscanf by default.
  if (command.length() < 3 || command[1] != ',') return;
  const char type = command[0];
  char *end = nullptr;
  const char *firstStart = command.c_str() + 2;
  const float first = strtof(firstStart, &end);
  if (end == firstStart || *end != ',') return;
  const char *secondStart = end + 1;
  const float second = strtof(secondStart, &end);
  if (end == secondStart || !isfinite(first) || !isfinite(second)) return;
 
  if (type == 'C') {
    if (*end != ',') return;
    const char *thirdStart = end + 1;
    const float third = strtof(thirdStart, &end);
    if (end == thirdStart || *end != '\0' || !isfinite(third) ||
        first < 100.0f || first > 4000.0f ||
        second < 100.0f || second > 4000.0f ||
        third < 10.0f || third > 100.0f ||
        floorf(first) != first || floorf(second) != second || floorf(third) != third) return;
    accelerationMs = static_cast<uint32_t>(first);
    brakingMs = static_cast<uint32_t>(second);
    configuredMaximumPercent = third;
    return;
  }
  if (*end != '\0') return;
  if (type == 'M' || type == 'I' || type == 'B' || type == 'P') {
    if (fabsf(first) > OUTPUT_LIMIT_PERCENT || fabsf(second) > OUTPUT_LIMIT_PERCENT) return;
    // P is a short-ramp opposite-wheel pivot; legacy I cannot bypass the gate.
    if (type == 'P' && (first * second >= 0.0f || fabsf(first + second) > 1.0f)) return;
    setTargets(first, second, type == 'P');
  }
}
 
void onRxWrite(uint16_t, BLECharacteristic *, uint8_t *data, uint16_t length) {
  String incoming;
  incoming.reserve(length);
  for (uint16_t i = 0; i < length; ++i) {
    incoming += static_cast<char>(data[i]);
  }
  for (size_t i = 0; i < incoming.length(); ++i) {
    const char c = incoming[i];
    if (c == '\n' || c == '\r') {
      if (receiveBuffer.length()) {
        processCommand(receiveBuffer);
        receiveBuffer = "";
      }
    } else if (receiveBuffer.length() < 80) {
      receiveBuffer += c;
    } else {
      receiveBuffer = "";
      neutralAndDisarm();
    }
  }
  if (receiveBuffer.length() && incoming.indexOf('\n') < 0 && incoming.indexOf('\r') < 0) {
    processCommand(receiveBuffer);
    receiveBuffer = "";
  }
}
 
void onBleConnect(uint16_t) {
  bleConnected = true;
  neutralAndDisarm();
}
 
void onBleDisconnect(uint16_t, uint8_t) {
  bleConnected = false;
  neutralAndDisarm();
  // Advertising restarts automatically through restartOnDisconnect(true).
}
 
void setup() {
  pinMode(BATTERY_PIN, INPUT);
  analogReference(AR_INTERNAL_3_0);
  analogReadResolution(12);
  pinMode(LED_RED, OUTPUT);
  digitalWrite(LED_RED, HIGH); // XIAO nRF52840 Sense RGB LED is active-low.
  pinMode(LEFT_ENCODER_A, INPUT);
  pinMode(LEFT_ENCODER_B, INPUT);
  pinMode(RIGHT_ENCODER_A, INPUT);
  pinMode(RIGHT_ENCODER_B, INPUT);
  leftPreviousState = (digitalRead(LEFT_ENCODER_A) << 1) | digitalRead(LEFT_ENCODER_B);
  rightPreviousState = (digitalRead(RIGHT_ENCODER_A) << 1) | digitalRead(RIGHT_ENCODER_B);
  attachInterrupt(digitalPinToInterrupt(LEFT_ENCODER_A), updateLeftEncoder, CHANGE);
  attachInterrupt(digitalPinToInterrupt(LEFT_ENCODER_B), updateLeftEncoder, CHANGE);
  attachInterrupt(digitalPinToInterrupt(RIGHT_ENCODER_A), updateRightEncoder, CHANGE);
  attachInterrupt(digitalPinToInterrupt(RIGHT_ENCODER_B), updateRightEncoder, CHANGE);
 
  attachMotorPwm();
  neutralAndDisarm();
 
  Bluefruit.begin(1, 0);
  Bluefruit.setName(DEVICE_NAME);
  Bluefruit.Periph.setConnectCallback(onBleConnect);
  Bluefruit.Periph.setDisconnectCallback(onBleDisconnect);
 
  motorService.begin();
 
  txCharacteristic.setProperties(CHR_PROPS_NOTIFY);
  txCharacteristic.setPermission(SECMODE_OPEN, SECMODE_NO_ACCESS);
  txCharacteristic.setMaxLen(128);
  txCharacteristic.begin();
 
  rxCharacteristic.setProperties(CHR_PROPS_WRITE | CHR_PROPS_WRITE_WO_RESP);
  rxCharacteristic.setPermission(SECMODE_OPEN, SECMODE_OPEN);
  rxCharacteristic.setMaxLen(128);
  rxCharacteristic.setWriteCallback(onRxWrite);
  rxCharacteristic.begin();
 
  Bluefruit.Advertising.addFlags(BLE_GAP_ADV_FLAGS_LE_ONLY_GENERAL_DISC_MODE);
  Bluefruit.Advertising.addTxPower();
  Bluefruit.Advertising.addService(motorService);
  Bluefruit.ScanResponse.addName();
  Bluefruit.Advertising.restartOnDisconnect(true);
  Bluefruit.Advertising.setInterval(32, 244);
  Bluefruit.Advertising.setFastTimeout(30);
  Bluefruit.Advertising.start(0);
 
  const uint32_t now = millis();
  lastCommandMs = now;
  lastControlMs = now;
  lastSpeedMs = now;
  lastTelemetryMs = now;
  // Offset battery notifications from the 250 ms encoder telemetry slots.
  lastBatteryMs = now - (BATTERY_INTERVAL_MS - 125);
  lastLedToggleMs = now;
}
 
void updateBatteryMonitor(uint32_t now) {
  if (now - lastBatteryMs >= BATTERY_INTERVAL_MS) {
    lastBatteryMs = now;
    const uint16_t count = analogRead(BATTERY_PIN);
    batteryVoltage = batteryVoltageFromAdc(count);
    if (!lowBattery && batteryVoltage < LOW_BATTERY_TRIP_V) lowBattery = true;
    else if (lowBattery && batteryVoltage >= LOW_BATTERY_CLEAR_V) lowBattery = false;
    // One short notification per second; this path never changes armed state or PWM.
    char message[24];
    snprintf(message, sizeof(message), "BAT,%.2f,%d\n", batteryVoltage, lowBattery ? 1 : 0);
    notifyLine(message);
  }
  if (!lowBattery) {
    if (redLedOn) { digitalWrite(LED_RED, HIGH); redLedOn = false; }
    lastLedToggleMs = now;
  } else if (now - lastLedToggleMs >= LED_TOGGLE_INTERVAL_MS) {
    lastLedToggleMs = now;
    redLedOn = !redLedOn;
    digitalWrite(LED_RED, redLedOn ? LOW : HIGH);
  }
}
 
void loop() {
  const uint32_t now = millis();
  updateSpeedEstimate(now);
 
  if (armed && now - lastCommandMs > SOFT_TIMEOUT_MS) {
    requestedLeft = 0.0f;
    requestedRight = 0.0f;
    requestedDirectPivot = false;
    waitingForNeutral = false;
    targetLeft = 0.0f;
    targetRight = 0.0f;
  }
  if (armed && now - lastCommandMs > HARD_TIMEOUT_MS) {
    neutralAndDisarm();
    notifyLine("STATE,TIMEOUT_DISARMED\n");
  }
 
  if (now - lastControlMs >= CONTROL_INTERVAL_MS) {
    const float dtSeconds = (now - lastControlMs) / 1000.0f;
    lastControlMs = now;
    const float targetEnvelope = max(fabsf(targetLeft), fabsf(targetRight));
    motionEnvelope = stepEnvelope(motionEnvelope, targetEnvelope, dtSeconds);
    if (targetEnvelope > 0.0f) {
      // In-motion steering changes wheel ratio immediately, without
      // restarting the full drive ramp or returning to neutral.
      rampedLeft = targetLeft * motionEnvelope / targetEnvelope;
      rampedRight = targetRight * motionEnvelope / targetEnvelope;
    } else {
      // Preserve wheel direction while braking the shared speed envelope.
      const float previousEnvelope = max(fabsf(rampedLeft), fabsf(rampedRight));
      const float factor = previousEnvelope > 0.0f ? motionEnvelope / previousEnvelope : 0.0f;
      rampedLeft *= factor;
      rampedRight *= factor;
      if (motionEnvelope <= 0.0f) rampPivotMode = false;
    }
    updateSynchroniser(dtSeconds, now);
  }
 
  if (now - lastTelemetryMs >= TELEMETRY_INTERVAL_MS) {
    lastTelemetryMs = now;
    int32_t leftSnapshot;
    int32_t rightSnapshot;
    taskENTER_CRITICAL();
    leftSnapshot = leftCount;
    rightSnapshot = rightCount;
    taskEXIT_CRITICAL();
    char message[128];
    snprintf(
      message,
      sizeof(message),
      "E,%ld,%ld,%.1f,%.1f,%.1f,%.1f,%.1f,%d,%d\n",
      static_cast<long>(leftSnapshot),
      static_cast<long>(rightSnapshot),
      leftRpm,
      rightRpm,
      appliedLeft,
      appliedRight,
      syncCorrection,
      armed ? 1 : 0,
      stallFault ? 1 : 0
    );
    notifyLine(message);
  }
 
  updateBatteryMonitor(now);
 
  delay(1);
}

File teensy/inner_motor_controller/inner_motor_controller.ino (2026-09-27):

#include <Servo.h>
#include <Encoder.h>

// ---------------- Pins and polarity: COPY the values you settled on in motor_sysid.ino ----------------
constexpr int S1_PIN = 5;     // left  (purple)
constexpr int S2_PIN = 3;     // right (brown)
constexpr int ENC_L_A = 22;   // left  white
constexpr int ENC_L_B = 21;   // left  yellow
constexpr int ENC_R_A = 20;   // right white
constexpr int ENC_R_B = 19;   // right yellow
constexpr int8_t LEFT_POLARITY  = 1;
constexpr int8_t RIGHT_POLARITY = 1;
constexpr int8_t ENC_L_POLARITY = 1;
constexpr int8_t ENC_R_POLARITY = -1;
constexpr float COUNTS_PER_WHEEL_REV = 64.0f * 70.0f;

constexpr int NEUTRAL_PULSE_US = 1500;
constexpr int PULSE_SPAN_US = 500;

// ---------------- Gains: PASTE from analyse_motor_id.m (one run per wheel) ----------------
constexpr float KP_L       = 1.001587f;  // % per (rad/s)
constexpr float KI_L       = 23.663865f;  // % per rad
constexpr float DEADBAND_L = 1.270f;  // % feedforward
constexpr float KP_R       = 1.152035f;  // % per (rad/s)
constexpr float KI_R       = 27.408961f;  // % per rad
constexpr float DEADBAND_R = 1.625f;  // % feedforward

// ---------------- Loop and safety settings ----------------
constexpr uint32_t TS_US = 10000;        // 10 ms, same as identification
constexpr float TS = TS_US * 1.0e-6f;
constexpr float MAX_PERCENT = 25.0f;     // actuator limit, same as identification
constexpr float OVERSPEED_RADS = 18.0f;  // above what the motor can do -> something is wrong
constexpr uint32_t SAT_ABORT_MS = 1500;  // saturated this long -> wrong sign, stall or bad gains
constexpr bool ZERO_REF_NEUTRAL = true;  // ref == 0 -> output exactly neutral and clear integrator
constexpr uint32_t COMMAND_TIMEOUT_MS = 500;  // no REF from the Pi this long -> stop the motors

// ---------------- PI controller ----------------

struct WheelPI {
  float kp;
  float ki;
  float deadband; // range of motor commands where motor does not move
  float integral;
};

WheelPI piL{KP_L, KI_L, DEADBAND_L, 0.0f};
WheelPI piR{KP_R, KI_R, DEADBAND_R, 0.0f};


float updatePI(WheelPI &controller, float reference, float measured) {

  // If we want the wheel stopped, send zero command
  // and reset the integral term
  if (reference == 0.0f) {
    controller.integral = 0.0f;
    return 0.0f;
  }

  // 1. Calculate velocity error
  float error = reference - measured;

  // 2. Proportional term
  float proportional = controller.kp * error;

  // 3. Deadband compensation
  float deadbandCompensation;

  if (reference > 0.0f) {
    deadbandCompensation = controller.deadband;
  }
  else {
    deadbandCompensation = -controller.deadband;
  }

  // 4. PI controller output before saturation
  float rawOutput =
      proportional
      + controller.integral
      + deadbandCompensation;

  // 5. Limit command to valid motor range
  float output = constrain(
      rawOutput,
      -MAX_PERCENT,
      MAX_PERCENT
  );

  // 6. Only build integral when it will not make
  // saturation worse
  bool saturatedHigh = rawOutput > MAX_PERCENT;
  bool saturatedLow  = rawOutput < -MAX_PERCENT;

  if (!saturatedHigh && !saturatedLow) {
    controller.integral += controller.ki * error * TS;
  }
  else if (saturatedHigh && error < 0.0f) {
    controller.integral += controller.ki * error * TS;
  }
  else if (saturatedLow && error > 0.0f) {
    controller.integral += controller.ki * error * TS;
  }

  return output;
}


// ---------------- Motor outputs ----------------
Servo leftMotorOutput;
Servo rightMotorOutput;

// Converts a PI percent command (-MAX_PERCENT..+MAX_PERCENT) into a
// Sabertooth R/C pulse width and writes it out.
void writeMotorCommand(Servo &motorOutput, float percentCommand, int8_t polarity) {
  percentCommand = constrain(percentCommand, -MAX_PERCENT, MAX_PERCENT);
  float pulseWidthUs = NEUTRAL_PULSE_US + percentCommand * polarity * PULSE_SPAN_US / 100.0f;
  motorOutput.writeMicroseconds((int)lroundf(pulseWidthUs));
}

void neutral() {
  writeMotorCommand(leftMotorOutput, 0.0f, LEFT_POLARITY);
  writeMotorCommand(rightMotorOutput, 0.0f, RIGHT_POLARITY);
}

// ---------------- Encoders ----------------
Encoder encL(ENC_L_A, ENC_L_B);
Encoder encR(ENC_R_A, ENC_R_B);

int32_t prevCountL = 0;
int32_t prevCountR = 0;

constexpr float COUNTS_TO_RAD_PER_SEC = 2.0f * PI / (COUNTS_PER_WHEEL_REV * TS);

// Returns wheel speed (rad/s) over the interval since this encoder was last read.
float measureWheelSpeed(Encoder &encoder, int32_t &prevCount, int8_t polarity) {
  int32_t count = polarity * encoder.read();
  float speed = (count - prevCount) * COUNTS_TO_RAD_PER_SEC;
  prevCount = count;
  return speed;
}

// ---------------- References: set by REF,<left>,<right> lines from the Pi ----------------
float referenceLeft = 0.0f;
float referenceRight = 0.0f;
uint32_t lastCommandMillis = 0;

// ---------------- Saturation tracking, for the SAT_ABORT_MS safety check ----------------
uint32_t satDurationMsL = 0;
uint32_t satDurationMsR = 0;

// ---------------- Per-cycle update: run once every TS seconds ----------------
void tick() {
  // 1. Measure wheel speed over the last interval
  float measuredLeft  = measureWheelSpeed(encL, prevCountL, ENC_L_POLARITY);
  float measuredRight = measureWheelSpeed(encR, prevCountR, ENC_R_POLARITY);

  // 2. Safety: overspeed means something is badly wrong (bad encoder read,
  // wrong polarity, wheel not actually loaded) -> stop immediately
  if (fabs(measuredLeft) > OVERSPEED_RADS || fabs(measuredRight) > OVERSPEED_RADS) {
    neutral();
    referenceLeft = 0.0f;
    referenceRight = 0.0f;
    Serial.println("#ABORT,OVERSPEED");
    return;
  }

  // 3. PI control -> motor commands
  float commandLeft  = updatePI(piL, referenceLeft, measuredLeft);
  float commandRight = updatePI(piR, referenceRight, measuredRight);

  // 4. Safety: pinned at the actuator limit for too long means wrong sign,
  // a stall, or bad gains -> stop before it does damage
  satDurationMsL = (fabs(commandLeft)  >= MAX_PERCENT) ? satDurationMsL + TS_US / 1000 : 0;
  satDurationMsR = (fabs(commandRight) >= MAX_PERCENT) ? satDurationMsR + TS_US / 1000 : 0;
  if (satDurationMsL > SAT_ABORT_MS || satDurationMsR > SAT_ABORT_MS) {
    neutral();
    referenceLeft = 0.0f;
    referenceRight = 0.0f;
    Serial.println("#ABORT,SATURATED_TOO_LONG");
    return;
  }

  // 5. Apply the commands and report what actually happened
  writeMotorCommand(leftMotorOutput, commandLeft, LEFT_POLARITY);
  writeMotorCommand(rightMotorOutput, commandRight, RIGHT_POLARITY);

  Serial.print("MEAS,");
  Serial.print(measuredLeft, 3);
  Serial.print(',');
  Serial.println(measuredRight, 3);
}
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

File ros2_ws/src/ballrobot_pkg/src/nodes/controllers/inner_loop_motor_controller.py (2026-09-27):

# Import the ROS2-Python package
import rclpy
from rclpy.node import Node
from rclpy.parameter import Parameter
from rclpy.qos import QoSProfile, QoSReliabilityPolicy, QoSHistoryPolicy

# Import numpy
import numpy as np

# Import package-specific messages

# DEFINE THE PARAMETERS
# > For the verbosity level of displaying info
DEFAULT_CONTROL_POLICY_VERBOSITY = 1
# Note: the levels of increasing verbosity are defined as:
# 0 : Info is not displayed. Warnings and errors are still displayed.
# 1 : Startup info is displayed.
# 2 : Info each control action and state estimate update is displayed.

# > For the wheel base of the robot [in meters]
DEFAULT_ROBOT_WHEEL_BASE = 0.22

# > For the wheel radius of the robot [in meters]
DEFAULT_ROBOT_WHEEL_RADIUS = 0.072

# > For the number of encoder counts per revolution of a wheel
# Pololu 70:1 37D motor with 64 CPR encoder, quadrature-decoded by the RoboClaw:
#   64 counts/motor-rev x 70 (gear ratio) = 4480 counts/wheel-rev
DEFAULT_ENCODER_COUNTS_PER_WHEEL_REVOLUTION = 4480

class InnerLoopMotorController(Node):
    """
    This class implements the inner-loop motor controller for the ballbot robot.
    It subscribes to the desired wheel velocities and publishes the corresponding motor commands.
    """

    def __init__(self):
        super().__init__('inner_loop_motor_controller')

        # Declare parameters
        self.declare_parameter('control_policy_verbosity', DEFAULT_CONTROL_POLICY_VERBOSITY)
        self.declare_parameter('robot_wheel_base', DEFAULT_ROBOT_WHEEL_BASE)
        self.declare_parameter('robot_wheel_radius', DEFAULT_ROBOT_WHEEL_RADIUS)
        self.declare_parameter('encoder_counts_per_wheel_revolution', DEFAULT_ENCODER_COUNTS_PER_WHEEL_REVOLUTION)

        # Get parameters
        self.control_policy_verbosity = self.get_parameter('control_policy_verbosity').get_parameter_value().integer_value
        self.robot_wheel_base = self.get_parameter('robot_wheel_base').get_parameter_value().double_value
        self.robot_wheel_radius = self.get_parameter('robot_wheel_radius').get_parameter_value().double_value
        self.encoder_counts_per_wheel_revolution = self.get_parameter('encoder_counts_per_wheel_revolution').get_parameter_value().integer_value

        # Set up QoS profile for subscriptions and publications
        qos_profile = QoSProfile(
            reliability=QoSReliabilityPolicy.RELIABLE,
            history=QoSHistoryPolicy.KEEP_LAST,
            depth=10
        )

        # publishers and subscribers
        # > Initialise a publisher for the motor duty cycle requests

        # > Initialise a subscriber for the current motor duty cycle

        # > Initialise a subscriber for the encoder counts sensor measurements

        

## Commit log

2026-09-21 reorg file structure, add interface node that receives theta_l_dot and theta_r_dot from teensy
2026-09-21 added tuning files - scripts, outputs, images - for reference, AI'd ino script for motor controller with PI gain values
    [motor_id_b_20260917_180222.csv, motor_id_l_20260917_170855.csv, motor_id_l_20260917_171906.csv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]
2026-09-22 add commands to readme, add clean script, add outputs folder for csvs to be processed locally
    [wheel_speed_cmd.csv, wheel_speed_meas.csv]
2026-09-22 run1 output
    [wheel_speed_cmd.csv, wheel_speed_log_run1.csv, wheel_speed_meas.csv]
2026-09-22 run2 output
    [wheel_speed_log_run2.csv]
2026-09-23 add template for publisher to teensy node
2026-09-23 added imu and uwb as nodes
2026-09-23 add csv output and new output folder structure for initial test with ball moving manually while sensor data being recorded
    [wheel_speed_cmd.csv, wheel_speed_log_run1.csv, wheel_speed_log_run2.csv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]
2026-09-24 fix port for uwb node
    [uwb_node.py]
2026-09-24 add logs from first enclosed run
    [cmd_vel_log_run1.csv, cmd_vel_log_run2.csv, cmd_vel_log_run20260924_191935.csv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]
2026-09-24 add logs from second enclosed run
    [cmd_vel_log_run20260924_192117.csv, imu_log_run20260924_192117.csv, uwb_log_run20260924_192117.csv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]
2026-09-24 Add CAD files
    CAD files for small ball robot, big ball robot and feeder box.
    [01_Main_Plate_3mm.SLDPRT, 02_Motor_Carrier_3mm.SLDPRT, 03_Standard_Electronics_Layer_3mm.SLDPRT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]
2026-09-25 fix output logic and add plotting script for matlab
    [cmd_vel_log_run1.csv, cmd_vel_log_run2.csv, cmd_vel_log_run20260924_191935.csv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]
2026-09-28 add solenopid release such that publishing from node on pi will release solenoid lock
2026-09-28 add solenoid changes for teensy
2026-10-06 add gui and imu streaming to cmpass on gui
2026-10-08 changed ble publisher to accept new imu messages
2026-10-08 changed the encoder message to publish standard wheel_states message
2026-10-08 added updated xiao code to handle encoder messages to pi
2026-10-08 updated encoder bridge
2026-10-11 changed run sensors to detect xiao and uwb via usb name instead of static port name.
2026-10-13 added uwb configuration file to run sensors script
2026-10-19 allowed for multiple solenoid triggers
2026-10-19 added filter to heading pos visualisation and offset
